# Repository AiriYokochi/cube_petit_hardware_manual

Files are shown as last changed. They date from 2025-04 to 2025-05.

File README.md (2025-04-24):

# cube_petit_hardware_manual

This is Hardware Assembly Manual for Cube petit v3

## Install

https://www.mkdocs.org/getting-started/

```
sudo apt install -y python3-pymdownx
pip install mkdocs
git clone https://github.com/AiriYokochi/cube_petit_hardware_manual.git
cd cube_petit_hardware_manual
mkdocs build
mkdocs serve --dev-addr=0.0.0.0:8000
```

access http://127.0.0.1:8000/

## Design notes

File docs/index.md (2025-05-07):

# Cube petit Hardware Manual
<br>
**Cube petitのハードウェア組み立てマニュアルです。**

完成品は**[こちら](./1_order/3_final_product.md)**から

---
## 基本仕様(ver3.0)
---

- 本体フレーム
    - 材質：アルミニウム
    - 外装：アクリル
    - 重さ：7[kg]
- センサー
    - 2D LiDAR
        - メーカー：
        - モデル：LD19
    - RGB-Dカメラ
        - メーカー:Intel
        - モデル：RealSense D435
        - 解像度：
        - フレームレート：
        - 深度範囲：
    - IMUセンサー
        - メーカー：
        - モデル：
    - AIカメラ
        - メーカー：
        - モデル：OAK-1
    - モータ
        - メーカー：DJI
        - モデル：M2006
    - ディスプレイ
        - HDMI 5inch

<br>

---
## 目次
---

##### [1.部品調達・発注(order)](./1_order/1_order.md)
##### [2.組み立て(assemble)](./2_assemble/2_assemble.md)
##### [3.PC設定&USB配線(pc_setting)](./3_pc_setting/3_pc_setting.md)
##### [4.センサ設定(sensor_setting)](./4_sensor_setting/4_sensor_setting.md)
##### [5.モーター設定(motor_setting)](./5_motor_setting/5_motor_setting.md)
##### [6.デバイステスト(device_test)](./6_device_test/6_device_test.md.md)
---

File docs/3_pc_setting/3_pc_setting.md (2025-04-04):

## PC設定&USB配線
<br>
MiniPCもしくはRaspberryPi5の設定をしてUbuntu24.04を導入します。<br>
Cube petit用のリポジトリをインストールして、次以降の章でセンサやMotorが正常に動くか確認します。
<br>

---
### 手順
---

##### [1.Ubuntu24.04の導入](./3-1.details/3-1_install_ubuntu.md)
##### [2.PCの設定](./3-1.details/3-2_setup_pc.md)
##### [3..ROS2 Jazzy導入](./3-1.details/3-3_setup_ros.md)
##### [4.配線](./3-1.details/3-4_wire.md)

---

**Pages**
[1.部品調達・発注(order)](./1_order/1_order.md)
[2.組み立て(assemble)](./2_assemble/2_assemble.md)
[3.PC設定(pc_setting)](./3_pc_setting/3_pc_setting.md)
[4.センサ設定(sensor_setting)](./4_sensor_setting/4_sensor_setting.md)
[5.モーター設定(motor_setting)](./5_motor_setting/5_motor_setting.md)

---

[indexに戻る](../index.md)

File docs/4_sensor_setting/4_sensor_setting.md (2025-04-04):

## センサー設定
<br>
センサーの設定をします。用途に合わせて必要なセンサを取り付けてください。
<br>

## LiDARの動作確認

LiDARをとPCは図のようにつながっています。

端末で以下のコマンドを叩きます。
```
ros2 launch cube_petit_bringup lidar_check.launch.py
```
画面が出てくるので、LiDARの赤い点が出ていることを確認してください。
確認したら**Ctrl**を押しながら**D**を押して終了します。

#### 動かないとき
LiDARが赤く光っていることを確認してください。

## 深度カメラ(Realsense)の動作確認

RealsenseとPCは図のようにつながっています。

端末で以下のコマンドを叩きます。
```

```
画面が出てくるので、画像が2つ出ていることを確認してください。
確認したら**Ctrl**を押しながら**D**を押して終了します。

#### 動かないとき

## AIカメラの動作確認

AIカメラとPCは図のようにつながっています。

端末で以下のコマンドを叩きます。
```
```
カメラの前で手をかざし、グーチョキパーをして、画面にPEACE,FIVEなどと出ていることを確認してください。
確認したら**Ctrl**を押しながら**D**を押して終了します。

#### 動かないとき

---

[indexに戻る](../index.md)
|[PC設定に戻る](../3_pc_setting.md)
|[次のページ](./3-2_setup_pc.md)

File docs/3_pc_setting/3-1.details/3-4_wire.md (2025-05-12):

## 配線設定

cube-petit用のPCをボディに入れて、USBハブやディスプレイとケーブル接続します。

## 必要なもの
- USBハブ3個(ELECOM, BUFFARO, ANKER)
- USBケーブル
    - typeA - micro-B (0.15[m]x1本) Display電源用
    - typeA - micro B (0.3[m]x1本) LiDAR用
    - typeA - type C (0.3[m]×2本) AIカメラ、CANable(モータ)
    - typeA - type C (0.3[m]×1本) 深度カメラ用
        - (PCにC端子がついていれば)typeC - type C (0.3[m])  
    - モバイルバッテリとPCを繋ぐケーブル(PCによる)
        - DC -> DC もしくは typeC -> typeC など
- HDMIケーブル
- アイソレータ モータ用
- SoundBlaster
- キーボード用のドングル(あれば)
- PC用のモバイルバッテリ PCによる、だいたい19Vで5A程度のもの
- モータ用のモバイルバッテリ 12V DC出力のもの
- 強力両面テープ([Monotaro](https://www.monotaro.com/p/7718/0173/?t.q=3M%2019mm%20%97%BC%96%CA%83e%81%5B%83v))
- 養生など適当なテープ [Monotaro](https://www.monotaro.com/p/0845/9193/?t.q=%97%7B%90%B6%83e%81%5B%83v%81%40%94%92)

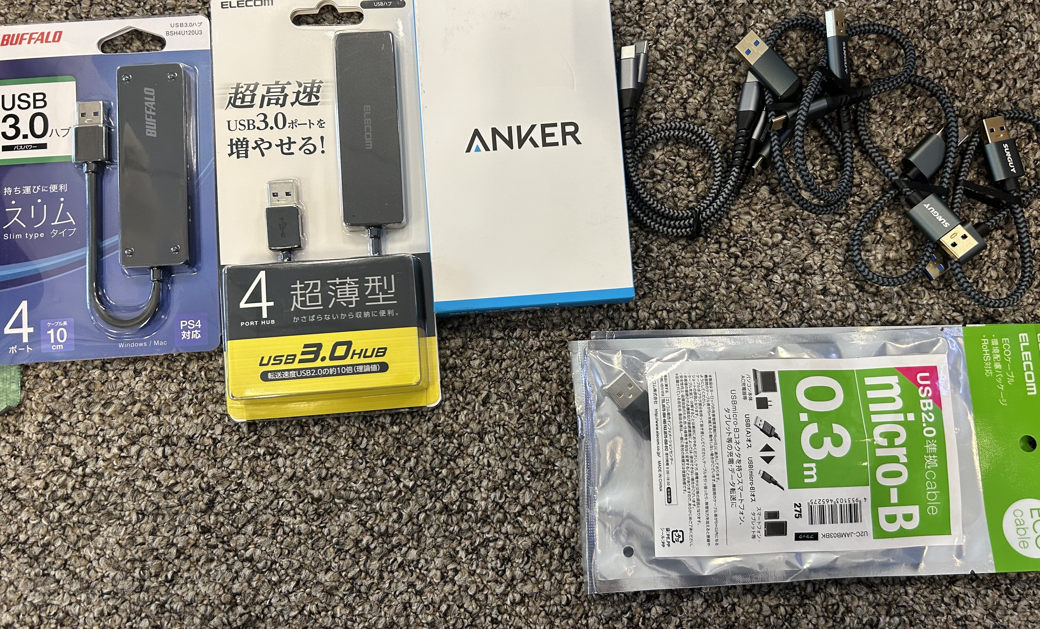
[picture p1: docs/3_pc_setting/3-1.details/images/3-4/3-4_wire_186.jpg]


## 手順①USBハブのとりつけ
ELECOMとBUFFAROのUSBハブに図のように両面テープを取り付けてボディの側面に貼る<br>
ELECOMが外側に来るように貼り付ける

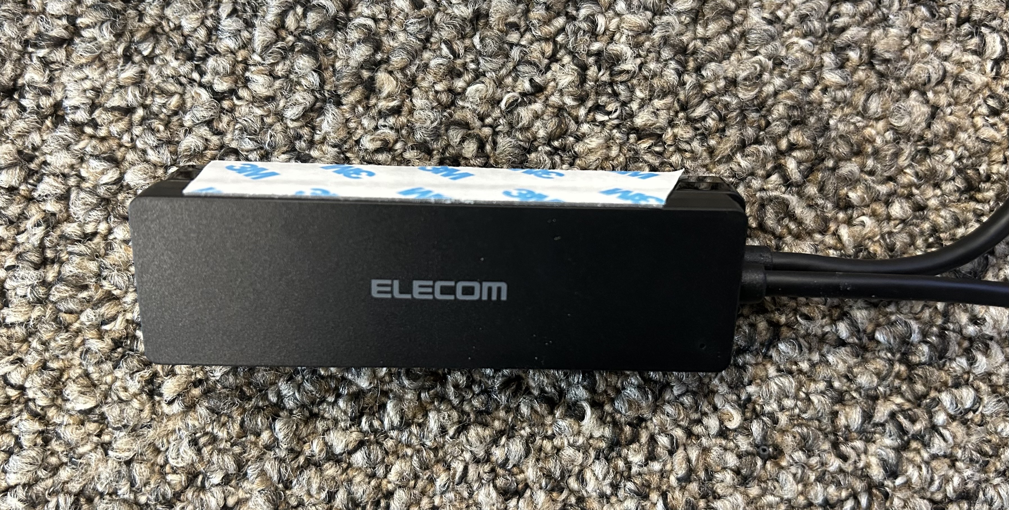
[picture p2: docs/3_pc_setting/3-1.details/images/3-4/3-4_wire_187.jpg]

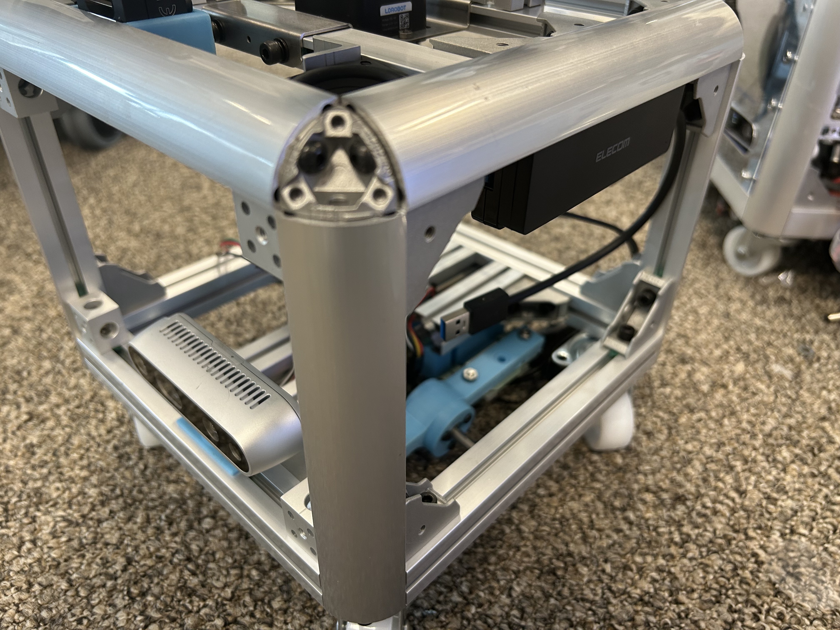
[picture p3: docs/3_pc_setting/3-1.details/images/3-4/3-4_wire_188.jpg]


## 手順②USBハブ配線
PCをボディの中にいれて配線を行います

### BUFFARO
側面1port<br>
- microBケーブル(0.15[m]) --- ディスプレイの電源用<br>

下面3ポート<br>
- typeCケーブル(0.3[m]) --- LiDAR用<br>
- SoundBlaster <br>
- スピーカアンプ<br>

### ELECOM
- typeCケーブル(0.3[m]) --- AIカメラ<br>
- キーボードドングル<br>
- typeCケーブル(0.3[m]) --- 深度カメラ(PCにtypeCポートがない場合)<br>
- ANKERのUSBハブ(PCにUSBポートが2つしかない場合)<br>

### ANKER
- アイソレータ --- typeA-typeC(0.3[m]) CANablePro用<br>

## 手順③HDMIケーブル
HDMIケーブルは写真のようにリボンケーブルを差し込んだら養生テープなどで絶縁しておく

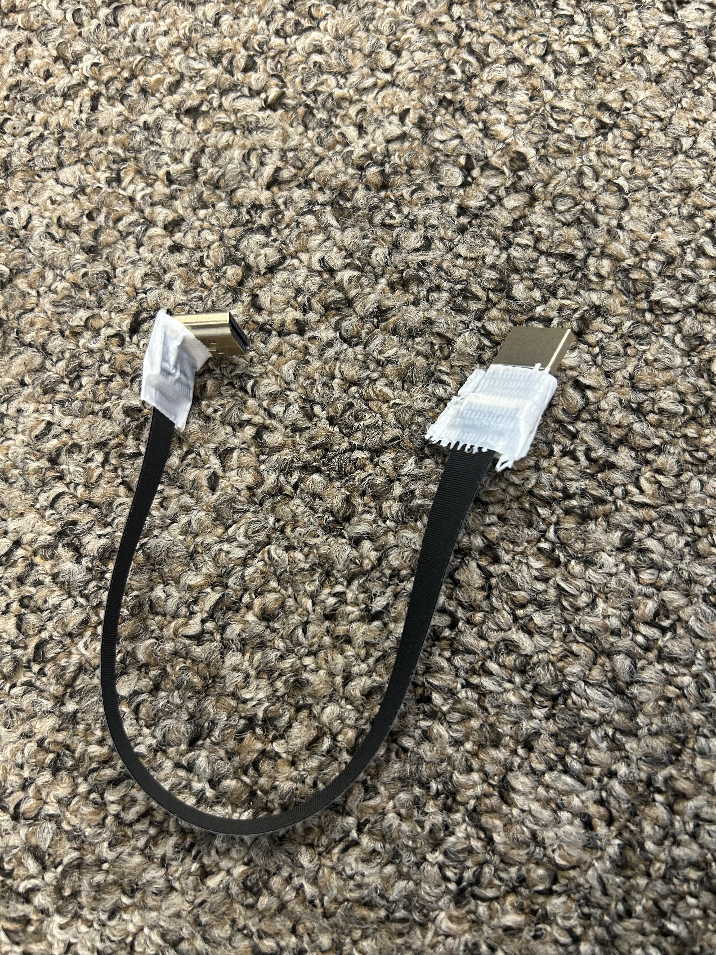
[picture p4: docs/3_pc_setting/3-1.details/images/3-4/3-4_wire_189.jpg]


[indexに戻る](../index.md)
|[PC設定に戻る](../3_pc_setting.md)
|[次のページ](../../4_sensor_setting/4_sensor_setting.md)

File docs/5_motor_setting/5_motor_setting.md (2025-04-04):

## モータ取り付け
<br>
モータの動作確認
<br>

## 必要なもの
- 12Vモバイルバッテリ
- モータ
- モータコントローラ
- PS4or5コントローラ
- アイソレータ

## 配線

## 自動CAN設定

```
ros2 launch cube_petit_hardware_interface cube_petit_control.launch.py
```

---
[indexに戻る](../index.md)

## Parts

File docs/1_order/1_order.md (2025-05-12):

## 部品調達・発注(Order)
<br>

#### **購入したらこちらのページでチェック**→ [次のページ](./2_check.md)

最新のBOMリストを確認してください。

購入するものと、3Dプリンタ及びアクリル板のレーザーカッター発注するものがあります。

部品調達は以下のサイトから行います。それぞれアカウントを作ってください。

- [Amazon](https://www.amazon.co.jp/)
- [Aliexpress](https://ja.aliexpress.com/)
- [Misumi](https://jp.misumi-ec.com/)
- [Monotaro](https://www.monotaro.com/)

---
## 搭載PCの選定について

---
入るサイズであればどのminiPCでもRaspberryPi4,5でも大丈夫ですが、<br>
スペックが低いと**動作が重い**、一定の機能が使えないなどの制限があります。<br>
スペックが高すぎると**バッテリーの持ちが悪くなる**、落ちるといった問題があります。<br>
丁度いいスペックのPCで購入可能なものを探していただけると助かります。<br>

**おすすめの機能**<br>

- サイズは幅12[cm]程度
- 電源を安定させたいならDCジャック、PDでも省電力(TDP15W~25W)のものを
- インターフェース
    - USB type A (3.0)が2個以上
    - HDMI
    - Bluetooth (コントローラとの接続)
    - Wifi (必須)
- CPUスペック
　- AMD Ryzen 7 6800U以下くらいで動きます。
　- GPUはいらないです
- RAM 32GB, SSD 512GB以上

**動作確認済みPC**<br>

- MINIFORUM EM680(2023/4) 参考価格７万円程度
- MINIFORUM S100(2024/4) 参考価格3万円程度(※リアルタイム会話機能が制限されます)
- [TODO]追加

---
## 購入
---

## 工具
ないものは借りるか購入してください
- はんだセット
- ニッパー
- ワイヤーストリッパー
- ヒートガン
- SMコネクタ・MOREXコネクタ用圧着工具

## 🛒 Amazon 購入品
<br>
2025/5月時点 Amazon総額: ¥42,950+(+自由分で ¥107,038)<br><br>

**必須**

  - **ディスプレイ　5inch、左右にHDMI端子がついているもの** – [Amazon](https://www.amazon.co.jp/gp/product/B07FDN3M8H) – ¥5,899

  - **USBハブ① 4portバスパワー(ELECOM)** – [Amazon](https://www.amazon.co.jp/gp/product/B00Y27DEVO) – ¥990

  - **USBハブ② 4portバスパワー(バッファロー)** – [Amazon](https://www.amazon.co.jp/gp/product/B07XPMR5CW) – ¥1,180

  - **USBハブ③ 4portバスパワー(ANKER)** – [Amazon](https://www.amazon.co.jp/Anker-%E3%82%A6%E3%83%AB%E3%83%88%E3%83%A9%E3%82%B9%E3%83%AA%E3%83%A0-%E3%82%B1%E3%83%BC%E3%83%96%E3%83%AB%E3%80%904%E3%81%A4%E3%81%AE-MacBo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) – ￥990

  - **SoundBlaster** – [Amazon](https://www.amazon.co.jp/Creative-Blaster-%E3%82%A4%E3%83%B3%E3%82%BF%E3%83%BC%E3%83%95%E3%82%A7%E3%83%BC%E3%82%B9-%E3%83%8F%E3%82%A4%E3%83%AC%E3%82%BE%E5%86%8D%E7%9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) – ¥1,645

  - **スピーカーアンプ** – [Amazon](https://www.amazon.co.jp/gp/product/B084FRZ4TV) – ¥670

  - **TAMIYA ホイール** – [Amazon](https://www.amazon.co.jp/gp/product/B0000WRY9I) – ¥605

  - **TAMIYA タイヤ** – [Amazon](https://www.amazon.co.jp/gp/product/B0834D138W) – ¥925

  - **TAMIYA タイヤインナー** – [Amazon](https://www.amazon.co.jp/gp/product/B0000WRXVM) – ¥780

  - **TAMIYA 瞬間セッチャク剤 (ゴムタイヤ用]**[Amazon)](https://www.amazon.co.jp/dp/B00061HCDQ/?coliid=I3RERL5PN6Q3JI&colid=58Z7IVI1DNDH&psc=1&ref_=lv_ov_lig_dp_it) ￥495

  - **ばね蝶番** – [Amazon](https://www.amazon.co.jp/gp/product/B00KQFC47G) – ¥1,056（2個）
  
  - **リボンケーブル**  – [Amazon](https://amzn.asia/d/iaFem4J) ￥1,161

  - **12Vモバイルバッテリ×2**  – [Amazon](https://www.amazon.co.jp/%E3%82%B5%E3%83%B3%E3%83%AF%E3%83%80%E3%82%A4%E3%83%AC%E3%82%AF%E3%83%88-%E3%83%A2%E3%83%90%E3%82%A4%E3%83%AB%E3%83%90%E3%83%83%E3%83%86%E3%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) ￥9,970

   - **USBケーブルC-C PD用 0.3[m]** - [Amazon](https://amzn.asia/d/amBpY5x) ￥899

   - **USBケーブルmicroB-A Display用  0.15[m] x1** - [Amazon](https://amzn.asia/d/09TgPOd)  ¥379 1本
   
   - **USBケーブルmicroB-A LiDAR用  0.30[m] x1** - [Amazon](https://amzn.asia/d/8nq8SEj) ¥376 1本

   - **USBケーブルC-A AIカメラ、深度カメラ、MotorController用  0.3[m] x3** - [Amazon](https://amzn.asia/d/1dJWg35)　¥1498 (2個)
   
   - **USBケーブルA-A  0.3[m]** - [Amazon](https://www.amazon.co.jp/GHNTJAP-5Gbps%E9%AB%98%E9%80%9F%E3%83%87%E3%83%BC%E3%82%BF%E8%BB%A2%E9%80%81-%E9%AB%98%E8%80%90%E4%B9%85%E3%83%8A%E3%82%A4%E3%83%AD%E3%83%B3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)　¥699
   
   - **PS4/5コントローラ** - [Amazon](https://www.amazon.co.jp/%E3%82%BD%E3%83%8B%E3%83%BC%E3%83%BB%E3%82%A4%E3%83%B3%E3%82%BF%E3%83%A9%E3%82%AF%E3%83%86%E3%82%A3%E3%83%96%E3%82%A8%E3%83%B3%E3%82%BF%E3%8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) ¥10,613

  - **SMコネクタ 3pinコネクタ (1セット)　ピン・ソケット(6セット)** [Amazon](https://amzn.asia/d/b40fbM0)￥650
  - (スピーカ用) SMコネクタ 2pinコネクタ ピン・ソケット(2セット) 上記に含まれる

**自由**

  - **マイク** – [Amazon](https://www.amazon.co.jp/RODE-Microphones-%E3%83%AD%E3%83%BC%E3%83%89%E3%83%9E%E3%82%A4%E3%82%AF%E3%83%AD%E3%83%95%E3%82%A9%E3%83%B3%E3%82%BA-%E3%83%AF%E3%82%A4%E3%8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) – ¥30,909
  - **モバイルバッテリ PD 140W 20V出力のもの** – [Amazon](https://www.amazon.co.jp/UGREEN-%E4%BD%8E%E9%9B%BB%E6%B5%81%E3%83%A2%E3%83%BC%E3%83%89%E3%83%BB%E3%83%91%E3%82%B9%E3%82%B9%E3%83%AB%E3%83%BC%E6%A9%9F%E8%83%BD%E6%90%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) – ¥13,580
  - **WiFiルータ** – [Amazon](https://www.amazon.co.jp/GL-iNet-GL-MT3000-%E3%83%88%E3%83%A9%E3%83%99%E3%83%ABIPv6%E5%AF%BE%E5%BF%9C-%E3%82%AE%E3%82%AC%E3%83%93%E3%83%83%E3%83%88AX3000-Wireguard/d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) – ¥13,999

  - **ワイヤレスキーボード** – [Amazon](https://www.amazon.co.jp/Logicool-%E3%83%AD%E3%82%B8%E3%82%AF%E3%83%BC%E3%83%AB-%E3%83%AF%E3%82%A4%E3%83%A4%E3%83%AC%E3%82%B9-%E3%82%BF%E3%83%83%E3%83%81%E3%82%AD%E3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) – ¥5,600

---

## 🌏 Aliexpress 購入品
<br>
2025/5月時点 Aliexpress総額: ¥43,521<br><br>

  - **スピーカ** – [Aliexpress](https://ja.aliexpress.com/item/32624188122.html) – ¥3,528（2個）

  - **USB to CAN** – [Aliexpress](https://ja.aliexpress.com/item/1005006008212111.html) – ¥2,163

  - **モータ** – [Aliexpress](https://ja.aliexpress.com/item/1005001417061496.html) – ¥22,626（2個）

  - **モータコントローラ** – [Aliexpress](https://ja.aliexpress.com/item/1005001417061496.html) – ¥13,924（2個）

  - **LiDAR LD19** – [Aliexpress](https://ja.aliexpress.com/item/1005006030979431.html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) – ¥12,388
 https://ja.aliexpress.com/item/1005006030979431.html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
  - **アイソレータ(モータコントローラ用)**  - [Aliexpress)](https://ja.aliexpress.com/item/4000047053305.html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) - ¥874 (1個)

   - **HDMIアダプター** [Aliexpress](https://ja.aliexpress.com/item/1005002393642419.html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) ¥406 (1個)

---

## 🧰 Monotaro 購入品
<br>
2025/5月時点 Monotaro総額: ¥25,462<br><br>

  - **キャスター** – [Monotaro](https://www.monotaro.com/g/00000812/?t.attr_f3506=%82%C8%82%B5&t.attr_f862=50&t.q=%83L%83%83%83X%83%5E%81%5B) – ¥876（4個）

  - **インシュロック** – [Monotaro](https://www.monotaro.com/p/3954/8731/?t.q=%83C%83%93%83V%83%85%83%8D%83b%83N%20%95%9D2.5) – ¥299（4本）

  - **モーターハブシャフト** - [Monotaro](https://www.monotaro.com/p/0568/6406/) - ￥499 (1個)

  - **強力両面テープ** ([Monotaro](https://www.monotaro.com/p/7718/0173/?t.q=3M%2019mm%20%97%BC%96%CA%83e%81%5B%83v)) ￥1,498 1個

  - **養生など適当なテープ** [Monotaro](https://www.monotaro.com/p/0845/9193/?t.q=%97%7B%90%B6%83e%81%5B%83v%81%40%94%92) ￥459 1個

### ねじ
- M4
    - 六角穴付ボルト / 素材：(SCM435/黒色酸化皮膜) / 全ねじ / 滑り止め付き / 長さ10[mm] (82本)：アルミフレーム組み立て用＋センサパーツ取付用 [Monotaro](https://www.monotaro.com/g/00010518/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) 2個 ￥1498
    - 六角穴付ボルト/ 素材：ステンレス / 全ねじ / 長さ35[mm] (8本)：足回り取り付け用　[Monotaro](https://www.monotaro.com/p/6891/0704/?t.q=%98Z%8Ap%8C%8A%95t%83%7B%83%8B%83g%81%40M4) 1個 ￥1,298
    - 六角穴付ボルト / 素材：ステンレス / 全ねじ/ 長さ8[mm] / (8本) : 四角ブラケット取付用 [Monotaro](https://www.monotaro.com/p/2901/7775/?t.q=%98Z%8Ap%8C%8A%95t%83%7B%83%8B%83g%81%40M4) 1個 ￥729
    - 六角穴付ボルト/ 素材：ステンレス / 全ねじ / 長さ16[mm] (8本)：足回り取り付け用 [Monotaro](https://www.monotaro.com/p/2901/7818/?t.q=%98Z%8Ap%8C%8A%95t%83%7B%83%8B%83g%81%40M4) 1個 ￥729
    - 六角穴付ボルト / 極低頭 / 素材:SHSS  / 長さ10[mm] (2本) [Monotaro](https://www.monotaro.com/p/4927/7864/) ￥749
    - 六角穴付ボルト / 極低頭 / 素材:SHSS  / 長さ16[mm] (2本) [Monotaro](https://www.monotaro.com/p/4927/7882/) ￥839
    - 六角穴付ボルト / 極低頭 / 素材:SHSS  / 長さ8[mm] (20本:外装)(12本:キャスタ用) [Monotaro](https://www.monotaro.com/p/4927/7907/) 2セット ¥1418 

- M3
    -  六角穴付ボルト / 極低頭 /  素材：(SCM435/黒色酸化皮膜) / 全ねじ / 長さ8[mm] (6本)：モータ取り付け用 [Monotaro](https://www.monotaro.com/p/4927/7121/?t.q=M3%81%40%8B%C9%92%E1%93%AA) ￥449

- M2.5
    - 六角穴付きボルト / 素材：(SCM435/黒色酸化皮膜) / 全ねじ / 長さ6[mm] (3本)：LiDAR取り付け用 [Monotaro](https://www.monotaro.com/p/6890/8796/?t.q=%98Z%8Ap%8C%8A%95t%83%7B%83%8B%83g%81%40M4) 1個 　￥718
    - 六角穴付きボルト / 素材：(SCM435/黒色酸化皮膜) / 全ねじ / 長さ6[mm] (2本)：画面取り付け用　上に含む
　
- M6 ( or 1/4インチねじ)　※どちらでも可
    - 六角穴付きボルト / 素材：ステンレス / 全ねじ /　8[mm] (1本):深度カメラ用 [Monotaro](https://www.monotaro.com/p/2901/7924/) ￥729
    - 六角穴付きボルト / 素材：(SCM435/黒色酸化皮膜) / 全ねじ/　5[mm] (1本):AIカメラ用 [Monotaro(ステンレス・6mm)](https://www.monotaro.com/p/6891/0765/?t.q=%98Z%8Ap%8C%8A%95t%83%7B%83%8B%83g%81%40M6x5)￥1,198

### ナット・ワッシャー
- M4四角ナット・ナットホルダー(106個)：アルミフレーム組み立て用 - [Misumi](https://jp.misumi-ec.com/vona2/detail/221005480697/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) ￥3912 3セット
- M4後入れナット(あると便利) - [Misumi](https://jp.misumi-ec.com/vona2/detail/221005480552/?Brand=NIQ1&CategorySpec=00000173459%3A%3Ab) ￥1730 10個
- M4ワッシャー(12個) ：キャスター取り付け用 [Monotaro](https://www.monotaro.com/p/0553/0104/?t.q=M4%83%8F%83b%83V%83%83%81%5B) ￥869
- M4スプリングワッシャー(8個:足回り取り付け用)(12個:キャスター取り付け用) [Monotaro](https://www.monotaro.com/p/4552/2951/?t.q=M4%83%8F%83b%83V%83%83%81%5B) ￥599
- M4ナット (8個:足回り取り付け用)(6個 : 画面取り付け用)　[Monotaro](https://www.monotaro.com/p/2876/3457/?t.q=M4%83i%83b%83g%201%8E%ED) ￥209
- M2.5ナット (3個: LiDAR取り付け用)(2個: 画面取り付け用) [Monotaro](https://www.monotaro.com/p/2876/3430/?t.q=M4%83i%83b%83g%201%8E%ED)￥499

### ケーブル

**モータコントローラ用**
- リボンケーブル [Monotaro](https://www.monotaro.com/p/3496/3345/?t.q=%83%8A%83%7B%83%93%83P%81%5B%83u%83%8B) ￥1,498 1個
- ケーブル AWG20 / 赤緑黒 / [Monotaro](https://www.monotaro.com/p/6242/7059/) ¥899 1個
- DCプラグ丸形(Φ5.5×2.5mm) [Monotaro](https://www.monotaro.com/p/7592/9183/?t.q=DC%93d%8C%B9%83R%83l%83N%83%5E%81%402.5) ￥209, 1個

### 熱収縮チューブ
**モータコントローラ用**
- 透明 / Φ21 / [Monotaro](https://www.monotaro.com/p/5513/6506/) ¥389 1個
- 赤と黒 / Φ6.5 / [Monotaro](https://www.monotaro.com/p/3559/8166/?t.q=%94M%8E%FB%8Fk%83%60%83%85%81%5B%83u%81%40%90%D4) ¥999 1個

## 🛒 Misumi 購入品
<br>
2025/5月時点 Misumi総額: ¥24,973<br><br>

- **コネクタ(モータコントローラ用)**
  - Morex 3.5mmピッチ 電線対基板用 ウエハー ライトアングルタイプ 3pin 53259-0329 (1個) - [Misumi](https://jp.misumi-ec.com/vona2/detail/222000581572/?ProductCode=53259-0329) 92円 1個

- **ベーシックフレーム M4 シリーズ ヘビー級 AFS-2020-4**
  - 品物型番: AFS-2020-4-70
  - サイズ: 70mm
  - 個数: 4
  - 総計: 365円
  - 購入先: [Misumi](https://jp.misumi-ec.com/vona2/detail/221005477019/)

- **ベーシックフレーム M4 シリーズ ヘビー級 AFS-2020-4**
  - 品物型番: AFS-2020-4-45-T
  - サイズ: 45mm
  - 個数: 2
  - 総計: 429円
  - 購入先: [Misumi](https://jp.misumi-ec.com/vona2/detail/221005477019/)

- **コーナージョイント M4シリーズ**
  - 品物型番: CJR-2020-4
  - サイズ: 記載なし
  - 個数: 8
  - 総計: 4,092円
  - 購入先: [Misumi](https://jp.misumi-ec.com/vona2/detail/221005481654/)

- **ベーシックフレーム M4シリーズ ヘビー級 AFS-1020-4**
  - 品物型番: AFS-1020-4-180
  - サイズ: 180mm
  - 個数: 4
  - 総計: 832円
  - 購入先: [Misumi](https://jp.misumi-ec.com/vona2/detail/221005476984/)

- **M4シリーズ デルタブラケット ABLD-20-4**
  - 品物型番: ABLD-20-4-T
  - サイズ: 記載なし
  - 個数: 36
  - 総計: 9,504円
  - 購入先: [Misumi](https://jp.misumi-ec.com/vona2/detail/221005480743/)

- **M4シリーズ ブロックブラケット ABLB**
  - 品物型番: ABLB-2015-4-T
  - サイズ: 記載なし
  - 個数: 4
  - 総計: 2,240円
  - 購入先: [Misumi](https://jp.misumi-ec.com/vona2/detail/221005481430/)

- **M4シリーズ スタンダードブラケット ABL**
  - 品物型番: ABL-2015-4
  - サイズ: 記載なし
  - 個数: 4
  - 総計: 1,320円
  - 購入先: [Misumi](https://jp.misumi-ec.com/vona2/detail/221005480798/)

- **ベーシックフレーム M4シリーズ ヘビー級 AFSR-2020**
  - 品物型番: AFSR-2020-4-150-W
  - サイズ: 150mm
  - 個数: 4
  - 総計: 1,659円
  - 購入先: [Misumi](https://jp.misumi-ec.com/vona2/detail/221005477109/)

- **ベーシックフレーム M4シリーズ ヘビー級 AFSR-2020**
  - 品物型番: AFSR-2020-4-180-W
  - サイズ: 180mm
  - 個数: 8
  - 総計: 3,494円
  - 購入先: [Misumi](https://jp.misumi-ec.com/vona2/detail/221005477109/)

- **ベーシックフレーム M4シリーズ ヘビー級 AFSF-2020**
  - 品物型番: AFSF-2020-4-180
  - サイズ: 180mm
  - 個数: 4
  - 総計: 946円
  - 購入先: [Misumi](https://jp.misumi-ec.com/vona2/detail/221005477086/)

---

## 発注データ

---

## 金属板(Misumi)
[Misumi meviy](https://meviy.misumi-ec.com/ja-jp/)で発注してください。
<br>

| 名前|加工方法　 | 材質 　　| 表面処理　　　  | 個数 　|備考 | 
| -- | -- | -- | -- | -- | -- |
| [LiDAR_LD19_plate](./Metal_parts/) | 板金 |SUS304(2B) | なし |1 | LiDAR用
| [L_bracket_2](./Metal_parts/) | 板金 | A5052| アルマイト(白) |2  | 天板取り付け用L字ブラケット |
| [T_bracket_2](./Metal_parts/) | 板金 | A5052| アルマイト(白) | 2 | 天板取り付け用T字ブラケット |
| [hinge_metal_holder_1_x4](./Metal_parts/) | 板金 | A5052| アルマイト(白)| 4 | 蝶番取り付け用
| [hinge_metal_holder_2_x4](./Metal_parts/) | 板金 | A5052| アルマイト(白) | 4 | 蝶番取り付け用

<br>

---

## 3Dパーツ(どこでも可)
<br>
材質はPLAもしくはABSなどでお好きな色で発注してください

| 名前　　　 | 個数　　| 備考 |
| -- | -- | -- |
| [hinge_holder_x4](./3D_printing_parts/hinge_holder_x4.stl) | 4 | 蝶番取り付け
| [M2006p36?holder_x2](./3D_printing_parts/M2006p36_holder_x2.stl) | 2 | モーター取り付け
| [oak-1-mount_x1](./3D_printing_parts/oak-1-mount_x1.stl) | 1 | AIカメラ取り付け
| [realsense_mount_x1](./3D_printing_parts/realsense_mount_x1.stl) | 1 | 深度カメラ取り付け

---

## アクリル板(どこでも可)
Monotaroやはざいやなどでお好きな色＋透明の板を購入してカット処理を頼むか、<br>
素材は買わずにMisumiにある中から発注してください。

**①自作例　Monotaro(クリアブルー)**<br>
Monotaroで素材を買う例

| 名前 | メーカー | 型番　　　 | サイズ　　　 | 個数　 | 購入先URL |
| -- | -- | -- | -- | -- | -- |
| アクリル板(ライトブルー) | 光 | A700-2S | 厚さ2mm幅320mm長さ545mm | 1 | [MONOTARO](https://www.monotaro.com/p/4031/9517/) |
| アクリル板(ライトブルー) | 光 | A700-3S | 厚さ3mm幅320mm長さ545mm | 2 |  [MONOTARO](https://www.monotaro.com/p/8625/7614/) |
| アクリル板 透明色 | 光 | A000-3S | 厚さ3mm幅320mm長さ545mm | 3 | [MONOTARO](https://www.monotaro.com/p/0701/5775/) |
| アクリル板(透明) | ノーブランド | |厚さ1mm幅400mm長さ400mm | 1 | [MONOTARO](https://www.monotaro.com/p/4554/7372/) |

<br>

**②自作例　はざいや**<br>
パステルカラーは[はざいや](https://www.hazaiya.co.jp/)もおすすめ。<br>
レーザーカッターに入るように450mm*550mm 程度までのサイズにすること。

|材質　　　　| 色 　　　　|厚み[mm] |サイズ[mm]　　　　　　　　　　|枚数　|用途|
| --- | --- | --- | --- | ---|---|
|アクリル| 好きな色 | 2| 200x150~550x450 | 1 | 顔前面の外装
|アクリル| 好きな色 | 3 | 200x450~550x450 | 2 | 側面及び上面の外装
|アクリル| 透明 | 1 | 200x150~550x450 | 1 | 顔前面のカバー
|アクリル | 好きな色 | 3 | 200x150~550x450  | 1 | センサ・ディスプレイの

<br>

**③完全発注　Minumi meviy2D**

[Misumi meviy](https://meviy.misumi-ec.com/ja-jp/2dx/meviy2d/)にアクセスして
見積もり＆発注してください。好きなカラーで大丈夫です。

---

**Cutデータ(寸法付き、、Misumi発注用)**
<br>

| 名前 | 色 | 厚み[mm] | 個数 |　備考 | 
| -- | -- | -- | -- | -- |
| [out_top_color_3mm_size.dxf](./Laser_Cut_parts/) | 色付き |3mm | 1 | 外装天板 | 
| [out_side_color_3mm_size.dxf](./Laser_Cut_parts/) | 色付き |3mm | 3 | 外装側面 |
| [face1_clear_1mm_size.dxf](./Laser_Cut_parts/) | 透明 | 1mm | 1 | 外装顔1 |
| [face2_color_2mm_size.dxf](./Laser_Cut_parts/) | 色付き | 2mm | 1 | 外装顔2 |
| [display1_clear_3mm_size.dxf](./Laser_Cut_parts/) | 透明 | 3mm | 1 | ディスプレイ取り付け用 |
| [display2_clear_3mm_size.dxf](./Laser_Cut_parts/) | 透明 | 3mm | 2 | ディスプレイ取り付け用 |

<br>

**Cutデータ(寸法なし、自分でLaserCutする用)**
<br>

| 名前 | 色 | 厚み[mm] | 個数 |　備考 | 
| -- | -- | -- | -- | -- |
| [out_top_color_3mm.dxf](./Laser_Cut_parts/sketch/out_top_color_3mm.dxf) | 色付き |3mm | 1 | 外装天板 | 
| [out_side_color_3mm_x2.dxf](./Laser_Cut_parts/sketch/out_side_color_3mm_x3.dxf) | 色付き |3mm | 3 | 外装側面 |
| [face1_clear_1mm.dxf](./Laser_Cut_parts/sketch/face1_clear_1mm.dxf) | 透明 | 1mm | 1 | 外装顔1 |
| [face2_color_2mm.dxf](./Laser_Cut_parts/sketch/face2_color_2mm.dxf) | 色付き | 2mm | 1 | 外装顔2 |
| [display1_clear_3mm_.dxf](./Laser_Cut_parts//sketch/display1_clear_3mm.dxf) | 透明 | 3mm | 1 | ディスプレイ取り付け用 |
| [display2_clear_3mm_x2.dxf](./Laser_Cut_parts/sketch/display2_clear_3mm_x2.dxf) | 透明 | 3mm | 2 | ディスプレイ取り付け用 |

---

[indexに戻る](../index.md)|[次のページ](./2_check.md)

---

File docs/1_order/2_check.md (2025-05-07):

## 部品チェック(Check)
<br>
購入したもの・発注したものが届いたら必要なものをチェックします。<br>
組み立てやすくするために部材を分けておくのがおすすめです。

#### **オーダーページ**→ [前のページ](./1_order.md)

<br>
---

### アルミフレーム
26本あることを確認します。

| ✅ | 断面の形 | 長さ[mm] | 本数 | 
| --- | --- | --- | --- |
| | R型 | 180  | 8 |
| | R型 | 150 | 4
| | 薄型 | 180 | 4 | 
| | 正方形 | 180 | 4 |
| | 正方形 | 70 | 4 |
|  | 正方形 | 45 | 2 |

左上から
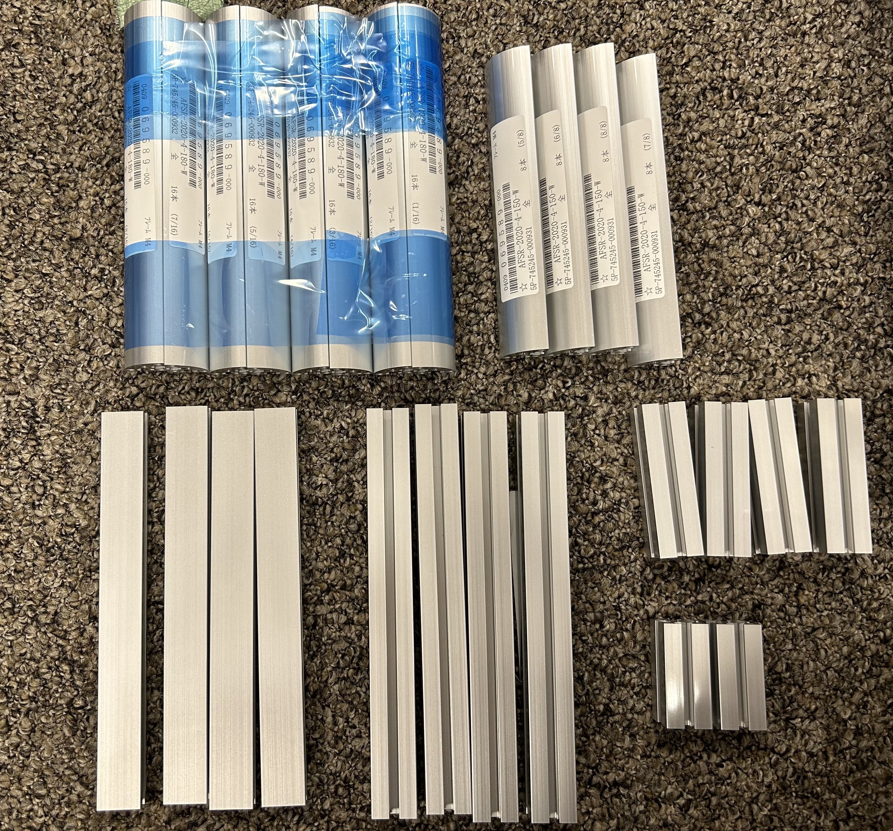
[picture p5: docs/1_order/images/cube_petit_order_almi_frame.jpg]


### アルミブラケット類・金属バーツ
以下があることを確認します

| ✅ | 形の説明 | 個数 |
| --- | --- | --- |
| | 顔面用の四角いブラケット | 4 | 
| | 三角のブラケット| 30 | 
| | L字のブラケット| 2 |
| | 角用の丸形ブラケット| 8 | 
| | LiDARマウント用金属パーツ | 1 |
| | 頭取り付け用用金属パーツ(T型) | 2 |
| | 頭取り付け用用金属パーツ(L型) | 2 |
| | 足回り用金属パーツ(小) | 4 | 
| | 足回り用金属パーツ(大) | 4 |

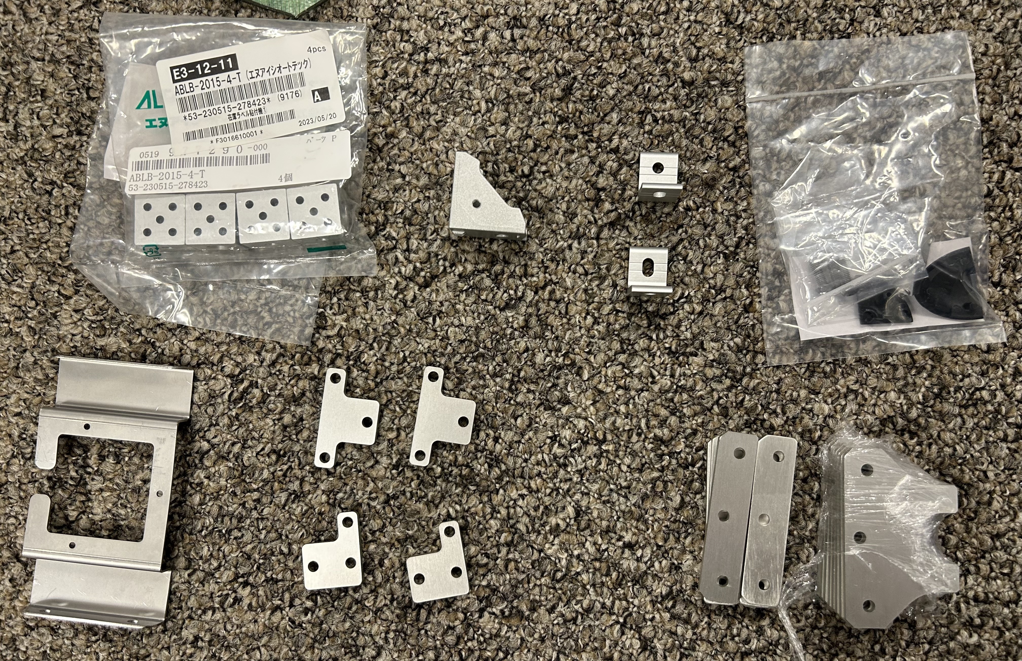
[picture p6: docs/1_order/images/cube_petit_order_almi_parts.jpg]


### 3Dプリンタ部品
以下があることを確認します

| ✅ | 説明 | 個数 | 
| --- | --- | --- |
|  | モータ取り付け用パーツ | 2 |
| | 足回り取り付けパーツ | 4 |
| | AIカメラ取り付けパーツ |1|
| | 深度カメラ取り付けパーツ | 1 |

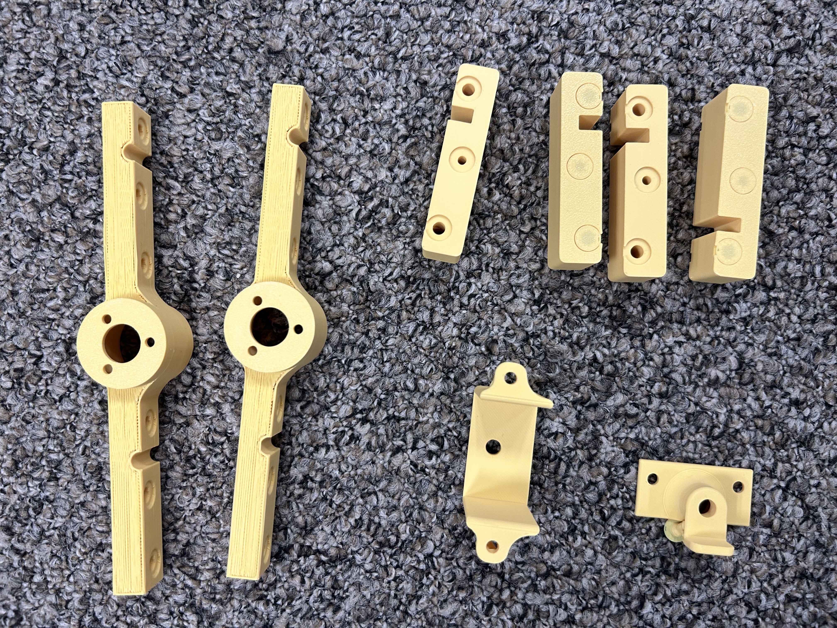
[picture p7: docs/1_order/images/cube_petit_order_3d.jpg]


### カメラ・センサ類
以下があることを確認します

| ✅ | 説明 | 個数 | 
| --- | --- | --- |
| | 深度カメラ(Realsense) |1|
| | AIカメラ(OAK-1) | 1 |
|  | LiDAR | 1 |

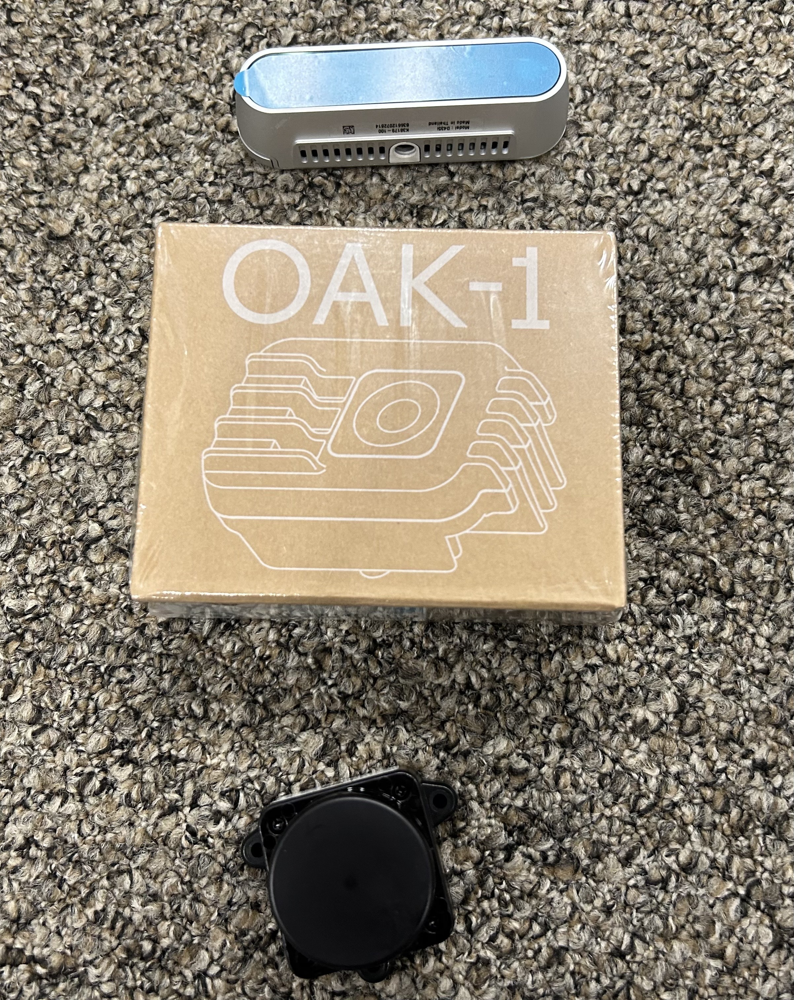
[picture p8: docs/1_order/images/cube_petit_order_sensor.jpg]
)

### 足回り部品
以下があることを確認します

| ✅ | 説明 | 個数 | 
| --- | --- | --- |
| | バネ蝶番 |4 |
| | インシュロック | 4 | 
| | キャスタ |4 |
| | モータ(M2006 P36) | 2 |
|  | モータコントローラ(C610) | 2 |
| | USBtoCAN(CANablePro) |1 |
| | ホイールインナー |2 |
| | ホイール |2 |
| | タイヤ |2 |
| | アイソレータ |1 |

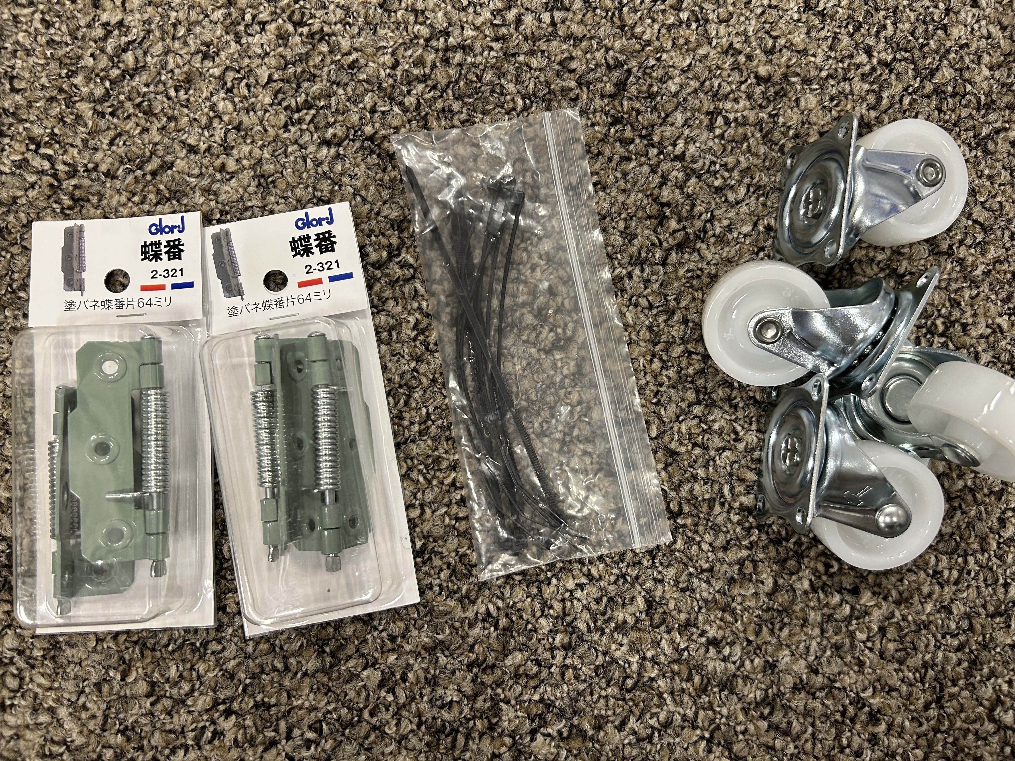
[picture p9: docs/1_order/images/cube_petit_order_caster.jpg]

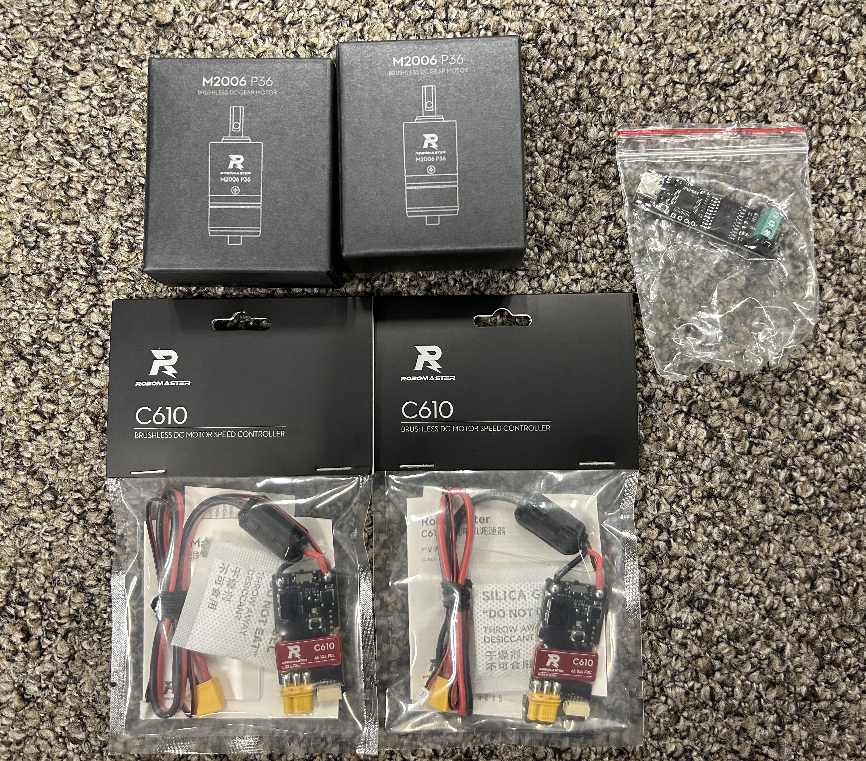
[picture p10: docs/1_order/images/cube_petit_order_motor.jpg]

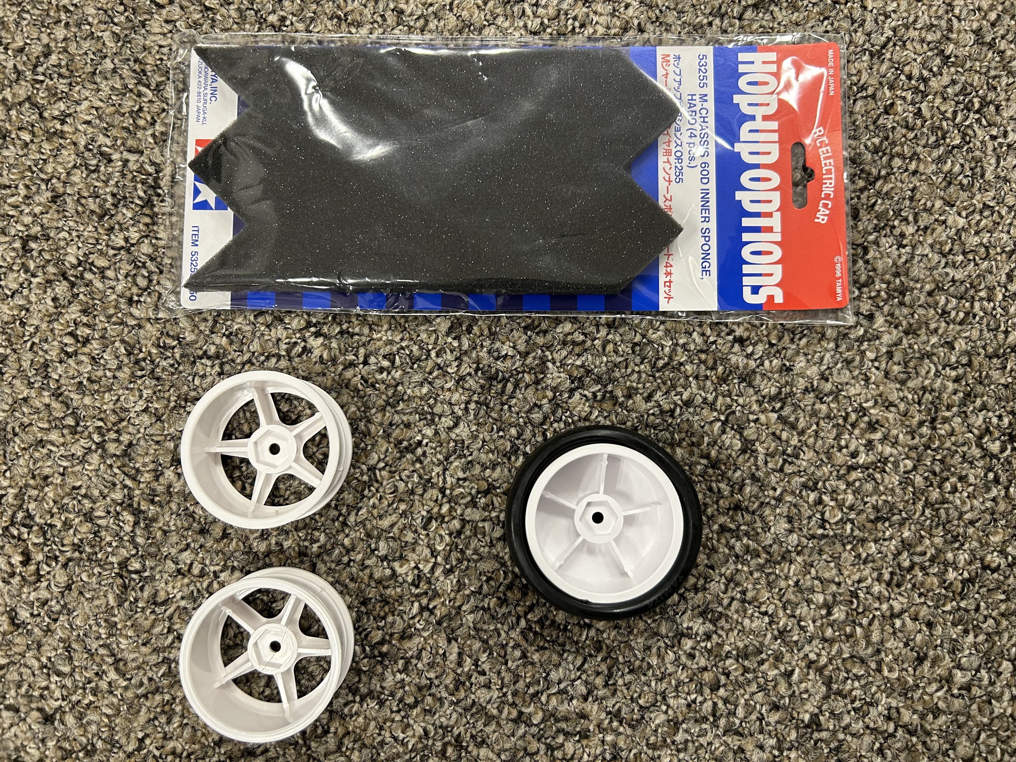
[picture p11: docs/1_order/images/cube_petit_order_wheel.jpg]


[TODO] アイソレータ・ホイールが来たら写真を更新する

### アクリル板
写真のように8枚があることを確認します

### ディスプレイ関連
写真のようにあることを確認します

| ✅ | 説明 | 個数 | 
| --- | --- | --- |
| | HDMIリボンケーブル1 | 1 |
| | HDMIリボンケーブル2 | 1 |
|  | ディスプレイ(ELECROW) | 1 |

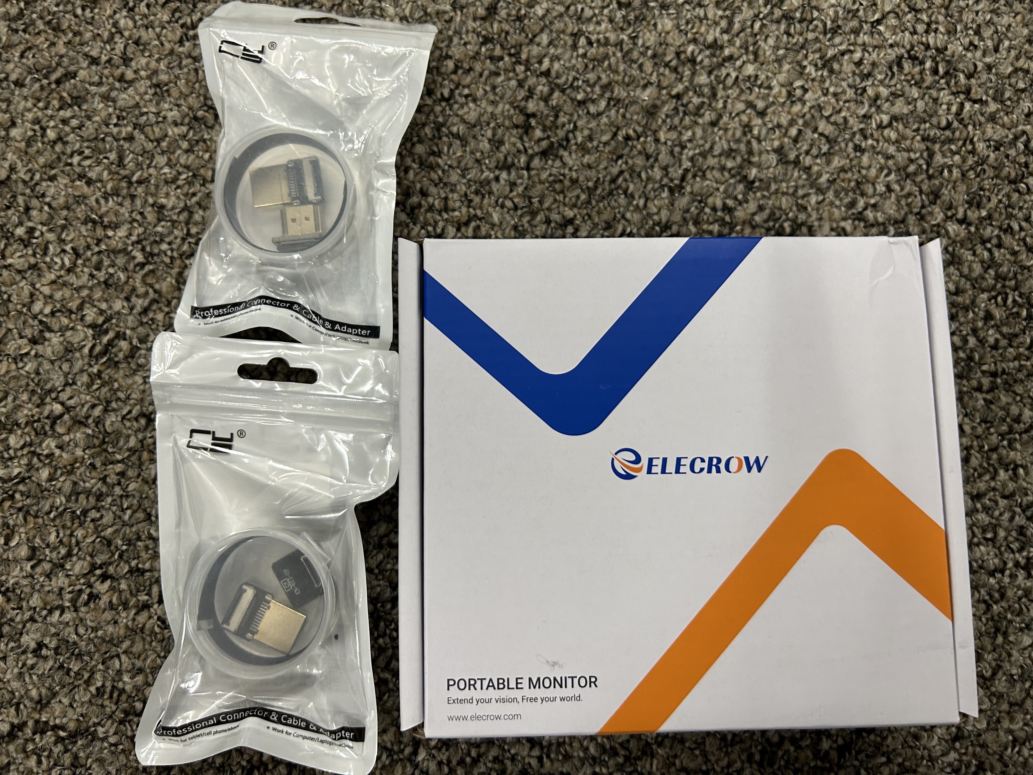
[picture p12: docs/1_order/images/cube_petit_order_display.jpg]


### USBケーブル・ハブ
写真のようにあることを確認します

| ✅ | 説明 | 個数 | 
| --- | --- | --- |
|  | A-A | | 
|  | A-microB | 2 |
|  | A-C | |
|  | バッファローのUSBハブ4Port |1|
|  | ELECOMのUSBハブ4Port | 2 |

### スピーカ・マイク
写真のようにあることを確認します

| ✅ | 説明 | 個数 | 
| --- | --- | --- |
|  | スピーカアンプ | 1 |
|  | スピーカ| 2 | 
|  | USB(Sound Braster!) | 1 |
|  | マイク | 1 |



[TODO] マイクの写真を追加

### PC・バッテリ関連
写真のようにあることを確認します

| ✅ | 説明 | 個数 | 
| --- | --- | --- |
|  | PC| 1 | 
|  | モバイルバッテリ | 1 |
|  | PC-モバイルバッテリのケーブル | 1 |

### ねじ・ナット・コネクタ

写真のように仕分けをしておくと楽です。<br>

アルミフレーム組み立て用<br>

その他パーツ組み立て用<br>


### 熱収縮チューブ
写真のようにあることを確認します

### ケーブル
写真のようにあることを確認します

---
[前のページ](./1_order.md) | [indexに戻る](../index.md) | [次のページ](../2_assemble/2_assemble.md)

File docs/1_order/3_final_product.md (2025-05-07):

## 完成品
フルキットです。PC・バッテリは要望に応じ選定し初期設定を行います<br>
[こちらのページ](./1_order.md)を参考にPCとバッテリの選定をしてください<br>

写真
※工場発注準備中(値段61万円程度)
<br><br>
**内訳**<br>
部品購入代(¥200,000)<br>
3Dプリント部品発注代(¥80,000)<br>
アクリル板発注代(¥80,000)<br>
金属部品発注代(¥130,000)<br>
PC購入+セットアップ代(¥100,000)<br>
バッテリ購入代(¥20,000)<br>
＋送料

選択可能オプション<br>
(センサはデフォルトですべてつきますが好きな機種がある場合は不要と書いてください。<br>部品代より値引きします)<br>

- センサ
    - [ ] AIカメラ:画像認識用<br>
    - [ ] 深度カメラ:自律移動用<br>
- 外装色<br>
    - [ ] クリアブルー<br>
    - [ ] クリアピンク<br>
    - [ ] クリアオレンジ<br>
    - [ ] アイボリー<br>
    - [ ] 白<br>
    - [ ] 黒<br>

---

## セミオーダー
必要なものは六角レンチのみで完成するキットです<br>
部品の注文・はんだづけ、熱収縮などの工程済み<br>
PC・バッテリは付属していません<br>

選択可能オプション(デフォルトでつきますが好きな機種がある場合は不要と書いてください。<br>部品代より値引きします)<br>
- [ ] AIカメラ:画像認識用<br>
- [ ] 深度カメラ:自律移動用<br>

写真<br><br>
※工場発注準備中(値段49万円程度)

**内訳**<br>
部品購入代(200,000)<br>
3Dプリント部品発注代(¥80,000)<br>
アクリル板発注代(¥80,000)<br>
金属部品発注代(¥130,000)<br>
＋送料

---

## DIY
35万円<br><br>
**内訳**<br>
部品購入代(¥140,000 ~ ¥200,000)<br>
3Dプリント部品代(¥0~ [DMM](https://lp.make.dmm.com/)の見積もりでは¥22,264)<br>
アクリル板代(~¥20000程度)<br>
金属部品発注代(¥0~Misumi meviyでは¥41,250)<br>
PC代(¥60,000~¥100,000)
バッテリ代(¥20,000)
+工具や設備代

---

## 問い合わせ先
at→`@`, dot→`.`

Mail: airi`<dot>`yokochi`<at>`g`<dot>`softbank`<dot>`co`<dot>`jp

[indexへもどる](./../index.md)

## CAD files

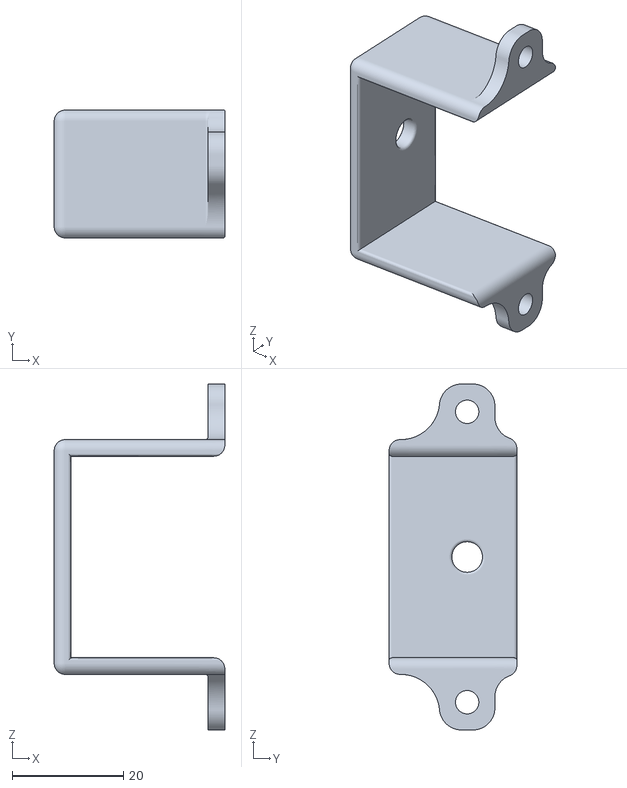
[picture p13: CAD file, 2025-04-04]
docs/1_order/3D_printing_parts/oak-1-mount_x1.stl
30.7 x 23.0 x 62.2

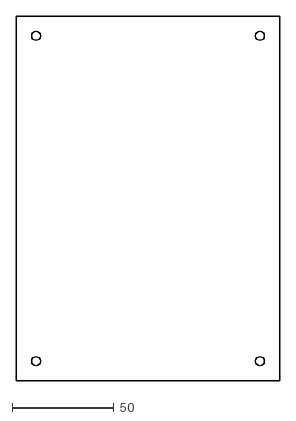
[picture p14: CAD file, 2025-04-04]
docs/1_order/Laser_Cut_parts/sketch/out_side_color_3mm_x3.dxf
129.4 x 179.4

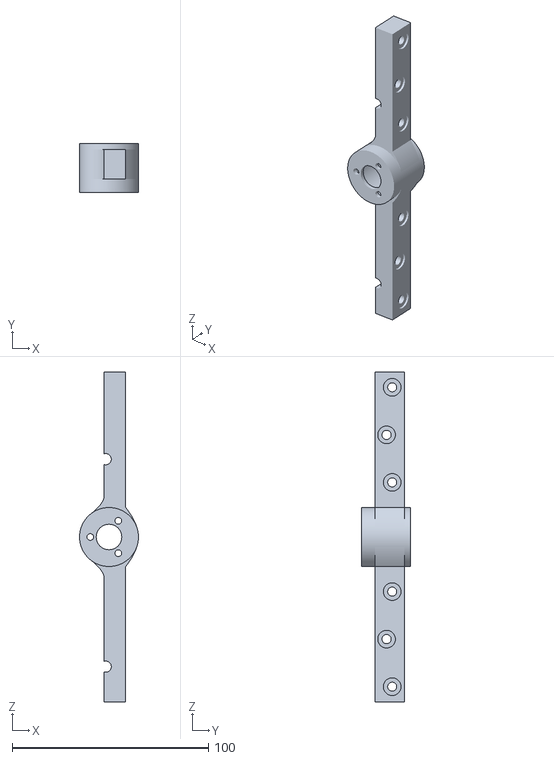
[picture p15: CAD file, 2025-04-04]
docs/1_order/3D_printing_parts/M2006p36_holder_x2.stl
30.0 x 25.0 x 168.0

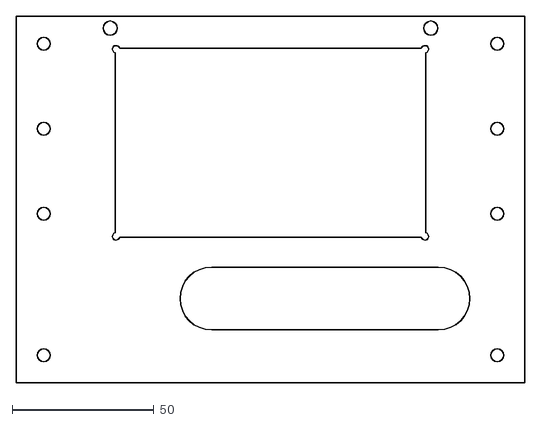
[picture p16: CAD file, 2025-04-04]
docs/1_order/Laser_Cut_parts/sketch/face2_color_2mm.dxf
179.4 x 129.4

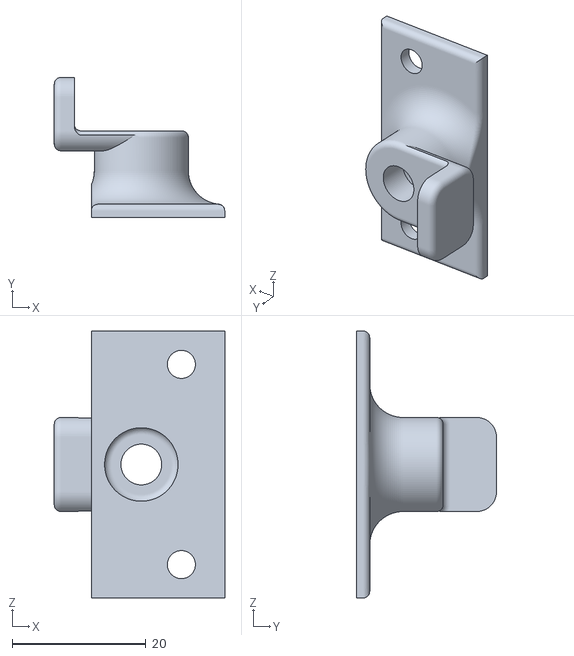
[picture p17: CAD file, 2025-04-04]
docs/1_order/3D_printing_parts/realsense_mount_x1.stl
25.6 x 21.0 x 40.0

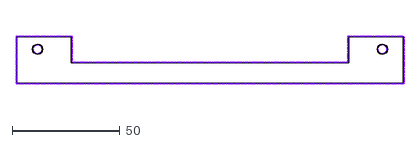
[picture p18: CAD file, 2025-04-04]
docs/1_order/Laser_Cut_parts/sketch/display2_clear_3mm_x2.dxf
180.0 x 22.0

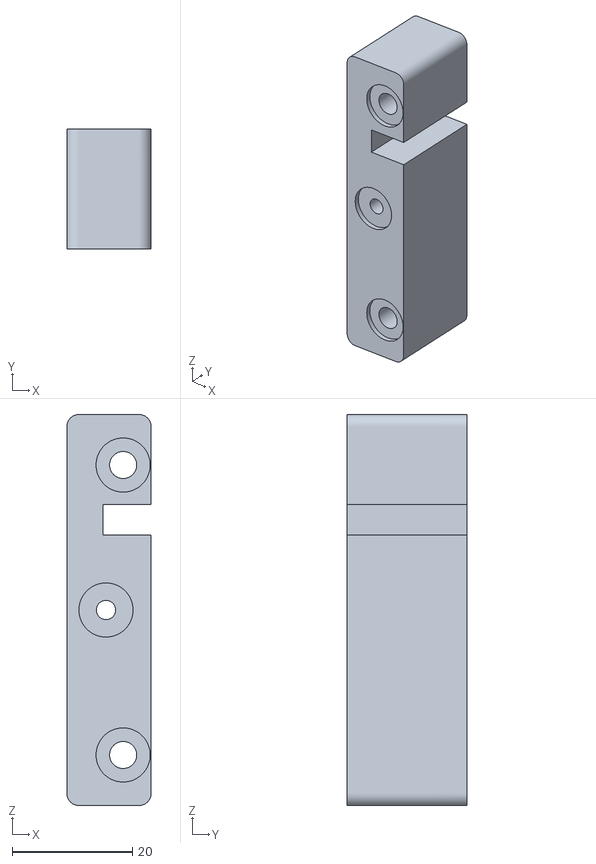
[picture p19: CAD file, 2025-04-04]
docs/1_order/3D_printing_parts/hinge_holder_x4.stl
14.0 x 20.0 x 65.0

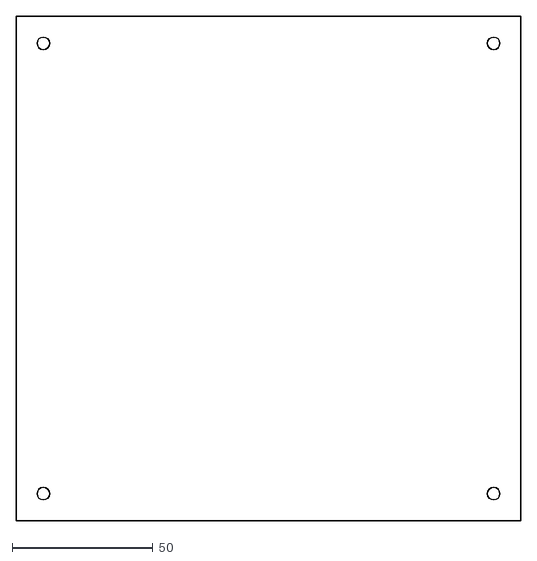
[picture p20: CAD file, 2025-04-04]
docs/1_order/Laser_Cut_parts/sketch/out_top_color_3mm.dxf
179.4 x 179.4

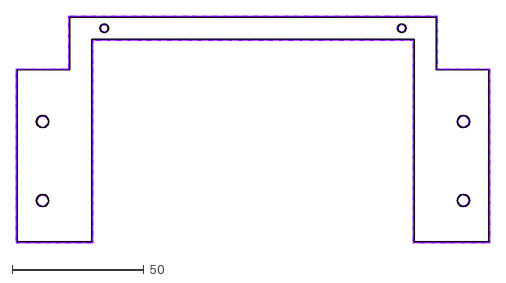
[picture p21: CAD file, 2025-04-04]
docs/1_order/Laser_Cut_parts/sketch/display1_clear_3mm.dxf
180.0 x 86.0

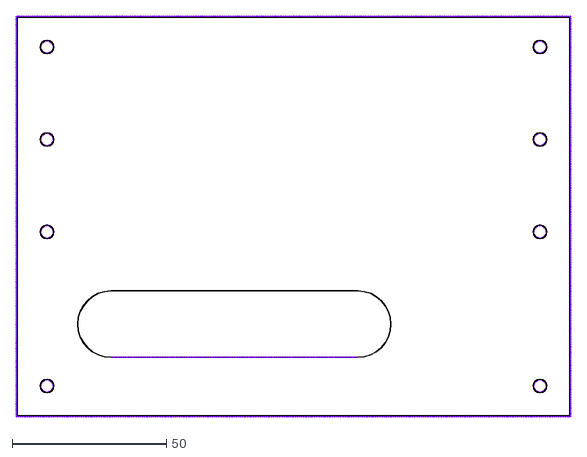
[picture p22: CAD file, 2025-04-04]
docs/1_order/Laser_Cut_parts/sketch/face1_clear_1mm.dxf
180.0 x 130.0

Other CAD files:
docs/1_order/Laser_Cut_parts/sized/3mm_clear_display1_size_x1.dwg
docs/1_order/Laser_Cut_parts/sized/1mm_clear_face1_size_x1.dwg
docs/1_order/Laser_Cut_parts/sized/3mm_clear_display2_size_x1.dwg
docs/1_order/Laser_Cut_parts/sized/3mm_color_out_top_size_x1.dwg
docs/1_order/Laser_Cut_parts/sized/3mm_color_out_side_size_x3.dwg
docs/1_order/Laser_Cut_parts/sized/2mm_color_face2_size_x1.dwg
docs/1_order/Almite_parts/L_almite_braket_3mm_x2.ipt
docs/1_order/Almite_parts/LiDAR_LD19_LD_Plate_1mm_x1.ipt
docs/1_order/Almite_parts/head_T_braket_alminium_3mm_x2.ipt
docs/1_order/Almite_parts/hinge_stopper1_alminium_3mm_x4.ipt
docs/1_order/Almite_parts/hinge_stopper2_alminium_3mm_x4.ipt
docs/1_order/Laser_Cut_parts/sized/idw/1mm_clear_face1_size_x1.idw
docs/1_order/Laser_Cut_parts/sized/idw/2mm_color_face2_size_x1.idw
docs/1_order/Laser_Cut_parts/sized/idw/3mm_clear_display1_size_x1.idw
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

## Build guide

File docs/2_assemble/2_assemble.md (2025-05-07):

## 組み立て(Assemble)

<br>

**力が必要な部分があります。注意してください**

<br>
---

### 手順
---

##### [1.顔](./2-1.details/2-1.face.md)
顔を組み立てます

##### [2.アルミフレーム](./2-1.details/2-2.almi_frame.md)
アルミフレームを組み立てます

##### [3.キャスター](./2-1.details/2-3.caster.md)
キャスターをアルミフレームに取り付けます

##### [4.タイヤ](./2-1.details/2-4.tyya.md)
タイヤを作ります

##### [5.足回り](./2-1.details/2-5.undercarrige.md)
足回りのバネを作ります

##### [6.モーターコントローラの設定](./2-1.details/2-6.motor_controller.md)
モーターコントローラの設定をします

##### [7.センサ](./2-1.details/2-7.sensor.md)
センサをアルミフレームに取り付けます

##### [8.スピーカの配線](./2-1.details/2-8.speaker_connector.md)
スピーカをボディに取り付けます

---

**Pages**
[1.部品調達・発注(order)](../1_order/1_order.md)
[2.組み立て(assemble)](../2_assemble/2_assemble.md)
[3.PC設定(pc_setting)](../3_pc_setting/3_pc_setting.md)
[4.センサ設定(sensor_setting)](../4_sensor_setting/4_sensor_setting.md)
[5.モーター設定(motor_setting)](..//5_motor_setting/5_motor_setting.md)
[6.デバイステスト(device_test)](../6_device_test/6_device_test.md.md)
---

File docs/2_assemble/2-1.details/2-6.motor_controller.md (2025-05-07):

## モーターコントローラの配線

モーターコントローラの配線をします。

---

## 必要な工具

- はんだ
- ニッパー
- ワイヤーストリッパー
- ヒートガン

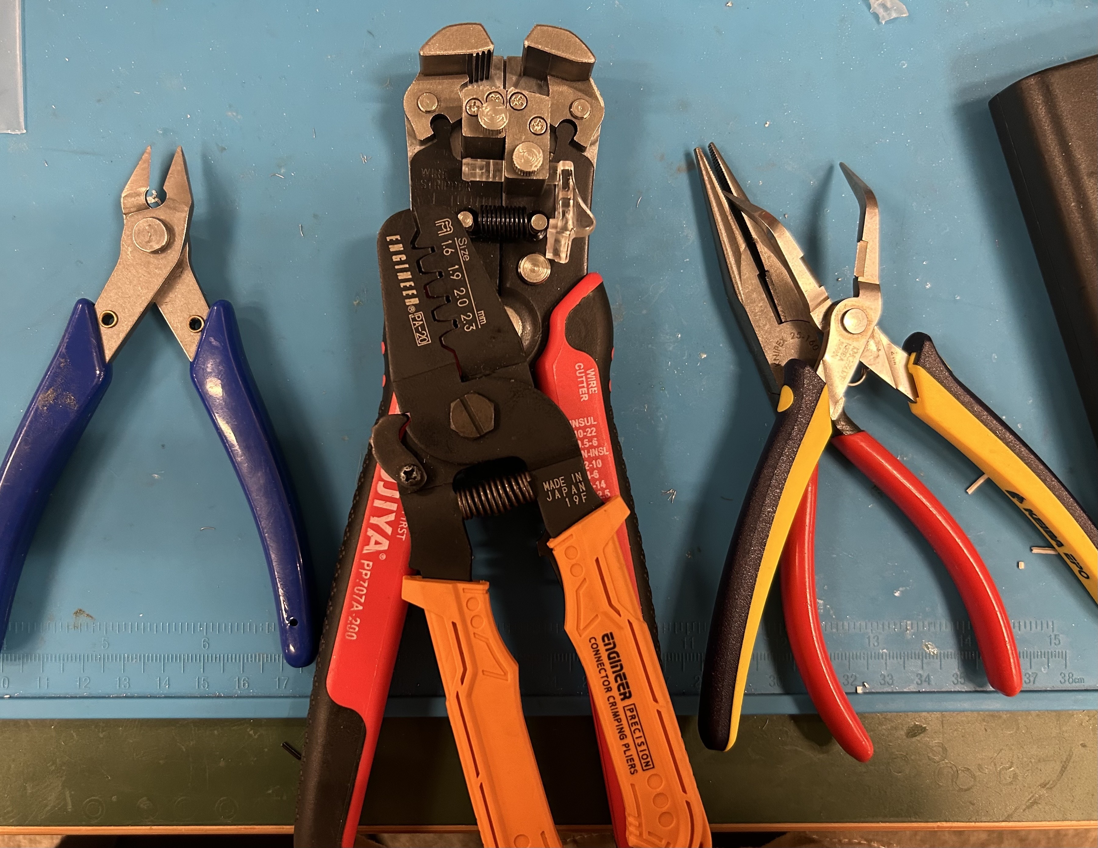
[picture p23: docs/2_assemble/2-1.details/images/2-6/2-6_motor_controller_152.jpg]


---

## 部材

- CANablePro(1個)

- Morex 3.25ピッチ電源コネクタ(基板L型 / 3pin /1個)
- Morex 3.25ピッチ電源コネクタ(ソケット / 3pin /1個)
- 5pinSMコネクタ(ソケット・コネクタ各1個)
- DC電源コネクタ(内径2.5mm)
- RoboMaster C610(x2)
- RoboMaster C610に付属の熱収縮チューブ(2本)
- 透明の熱収縮チューブ(Φ21)
- 赤の熱収縮チューブ(Φ6)
- 黒の熱収縮チューブ(Φ6)

- 赤, 緑, 黒のケーブル(AWG20　各1本)
- リボンケーブル
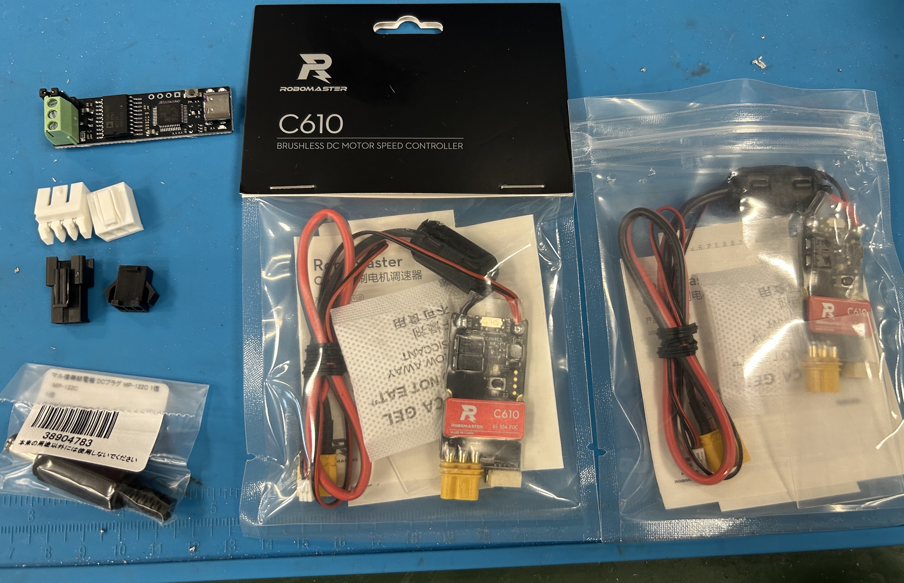
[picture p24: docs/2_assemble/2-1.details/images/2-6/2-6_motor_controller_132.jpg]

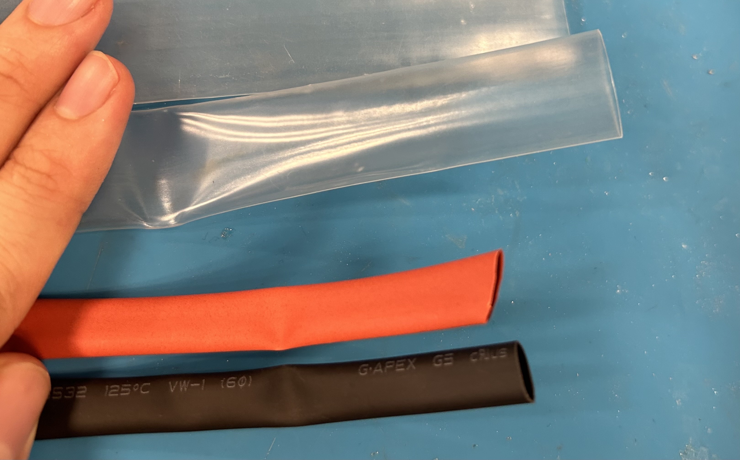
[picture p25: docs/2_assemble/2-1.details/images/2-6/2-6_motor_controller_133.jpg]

---

## 手順①ケーブル・熱収縮チューブのカット

赤黒緑のケーブルは120[mm]にカットする<br>
リボンケーブルは3芯だけむいて、120[mm]にカットしたものを2本つくる<br>
透明の熱収縮チューブは50[mm]にカット<br>
赤黒の熱収縮チューブは30[mm]にカット<br>

---

## 手順②CANableProのコネクタつけ
基板の裏を見てVer1.0か2.0か確認する<br>
Ver1.0の基板の方は右下のジャンパピンをTERMの方に切り替えます。<br>
3PINのコネクタを取り外します
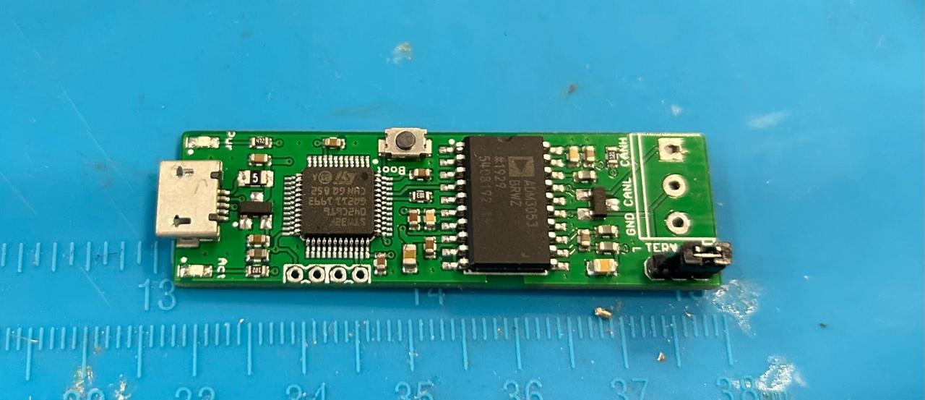
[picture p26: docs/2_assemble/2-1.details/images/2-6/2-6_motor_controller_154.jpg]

Morexの3Pinを取り付けます
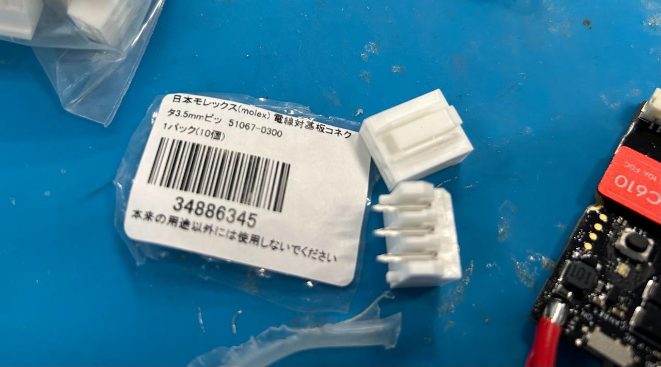
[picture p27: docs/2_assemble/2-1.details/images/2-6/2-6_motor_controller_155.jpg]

ここで基板のバージョンによってCANL, CANH, GNDの順が異なるので注意
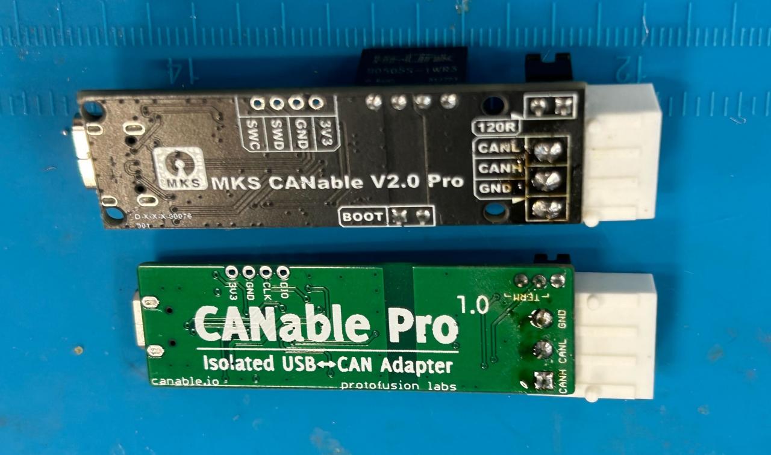
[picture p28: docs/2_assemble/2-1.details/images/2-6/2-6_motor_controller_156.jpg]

どれがどのピンか書いておくとわかりやすい
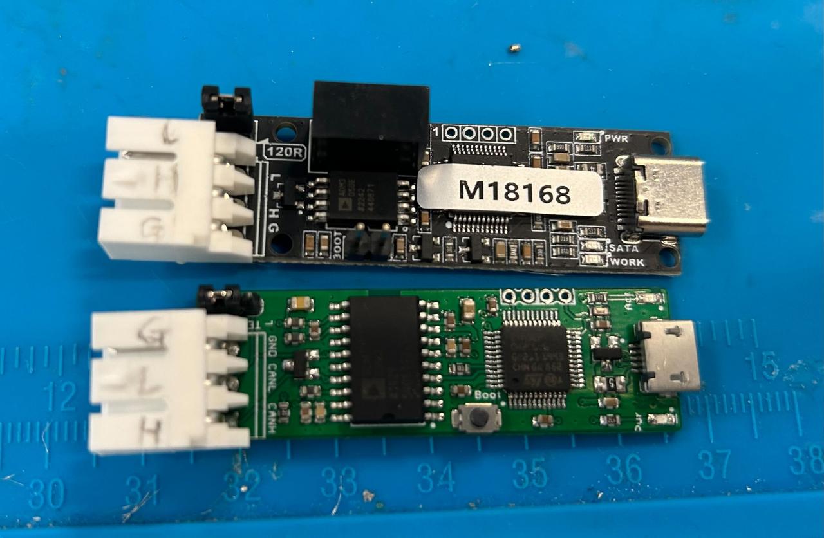
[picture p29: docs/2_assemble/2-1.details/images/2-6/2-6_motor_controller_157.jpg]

## 手順③CANableProとSMコネクタのケーブル作成
- 赤・黒・緑のケーブルを使ってケーブルを作成します<br>
- SMコネクタ<br>
　- 1番:GNDと黒ケーブルでつなぐ<br>
　- 2番:CANLと緑ケーブルでつなぐ<br>
　- 3番:CANHと赤ケーブルでつなぐ<br>

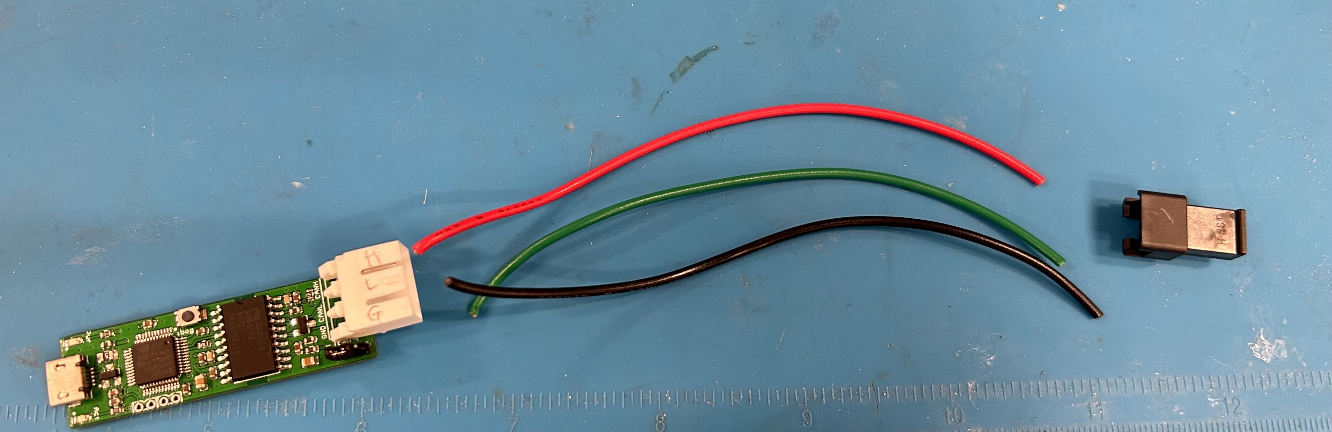
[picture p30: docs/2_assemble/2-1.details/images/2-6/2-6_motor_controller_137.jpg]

ワイヤーストリッパーで被膜をむく
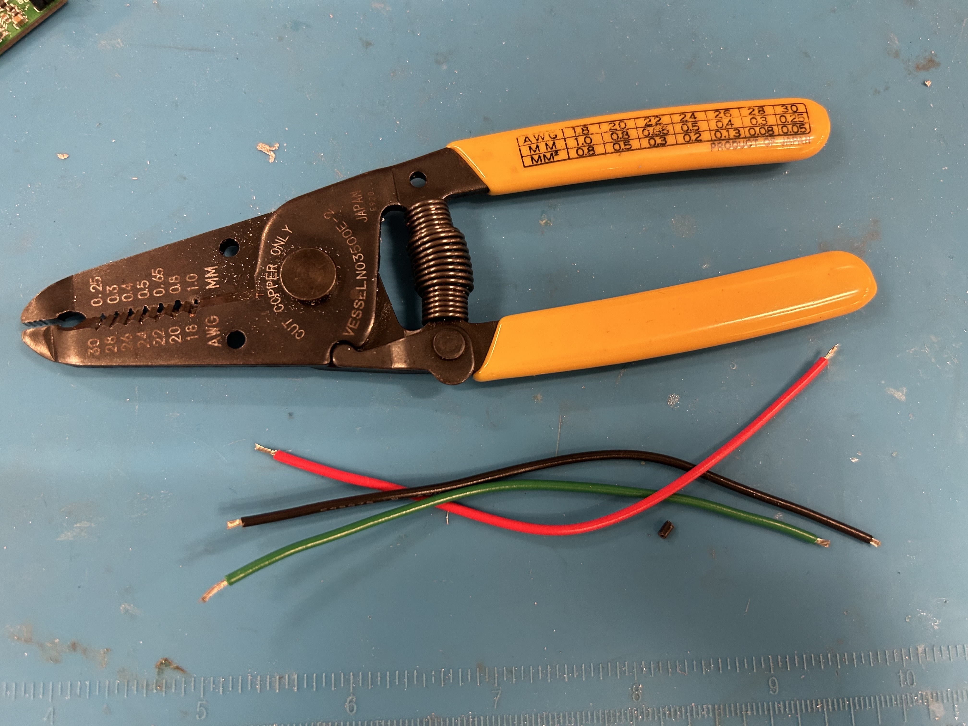
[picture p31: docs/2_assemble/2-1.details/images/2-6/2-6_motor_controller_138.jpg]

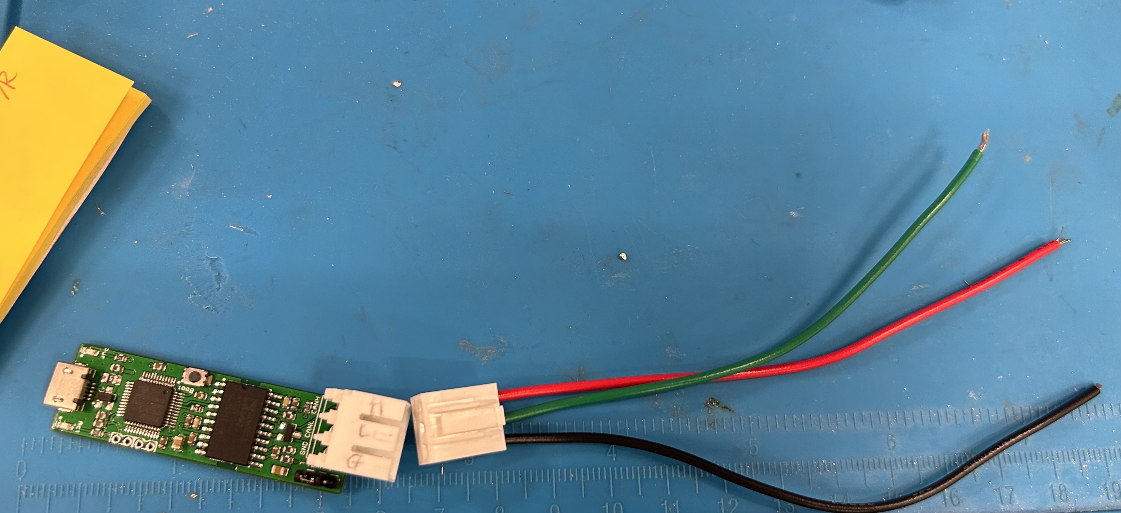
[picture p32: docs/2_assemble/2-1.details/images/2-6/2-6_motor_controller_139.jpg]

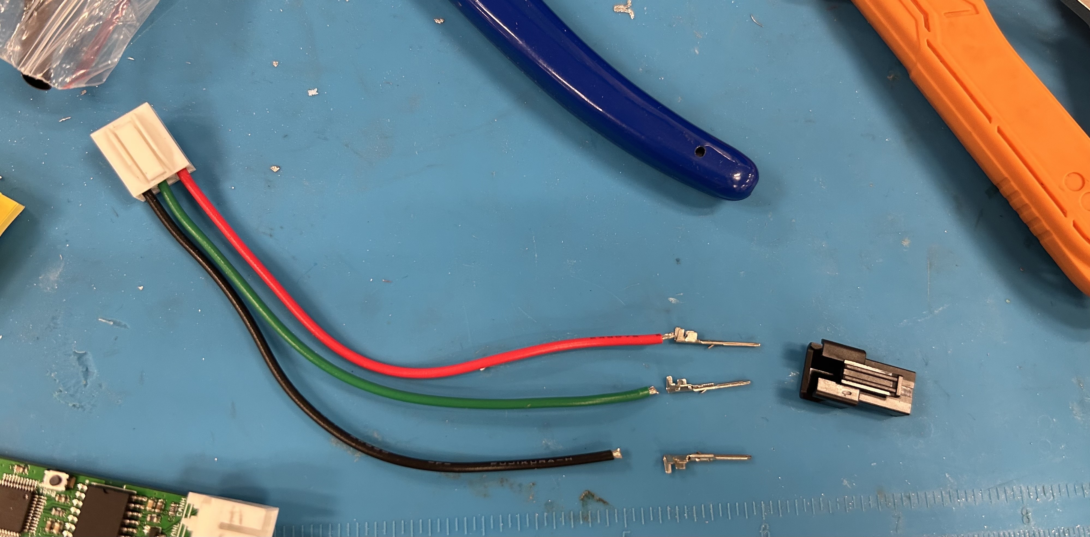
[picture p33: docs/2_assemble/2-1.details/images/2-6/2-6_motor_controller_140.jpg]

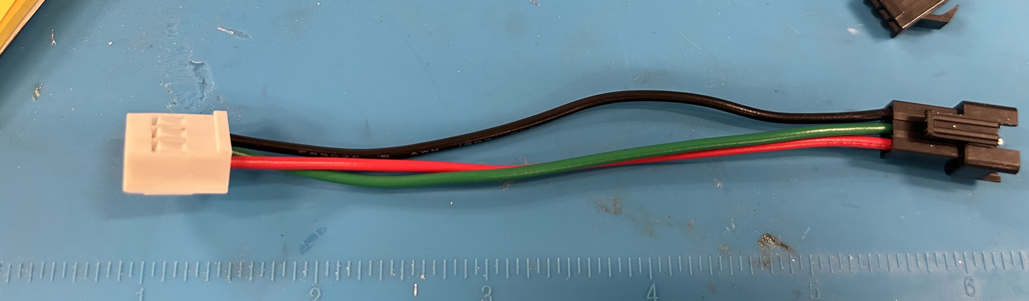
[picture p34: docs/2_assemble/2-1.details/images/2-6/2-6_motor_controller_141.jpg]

## 手順④モータコントローラの電源ケーブル作成
電源を120[mm]くらいのところでカットする<br>
細い線はいったんはんだをとっておく<br>
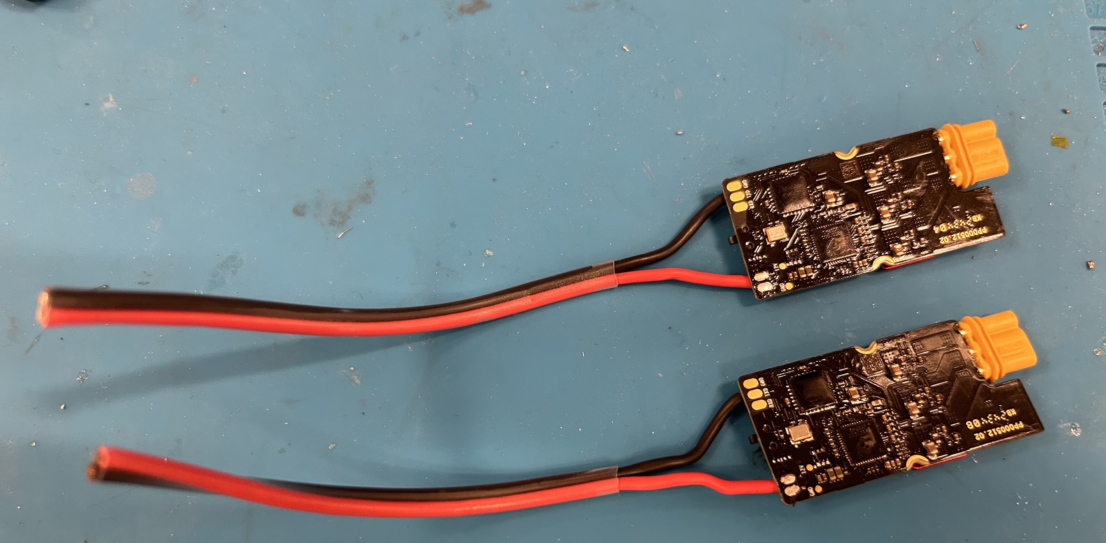
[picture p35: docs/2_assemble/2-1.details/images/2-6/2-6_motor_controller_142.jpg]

切った残りのケーブル1本と、モータコントローラにつながっている電源ケーブル2本<br>
切った残りのケーブル1本にΦ6の熱収縮チューブをいれておく<br>
合計3本×赤黒で6本の被膜を向いて電源とGNDそれぞれまとめてはんだづけ
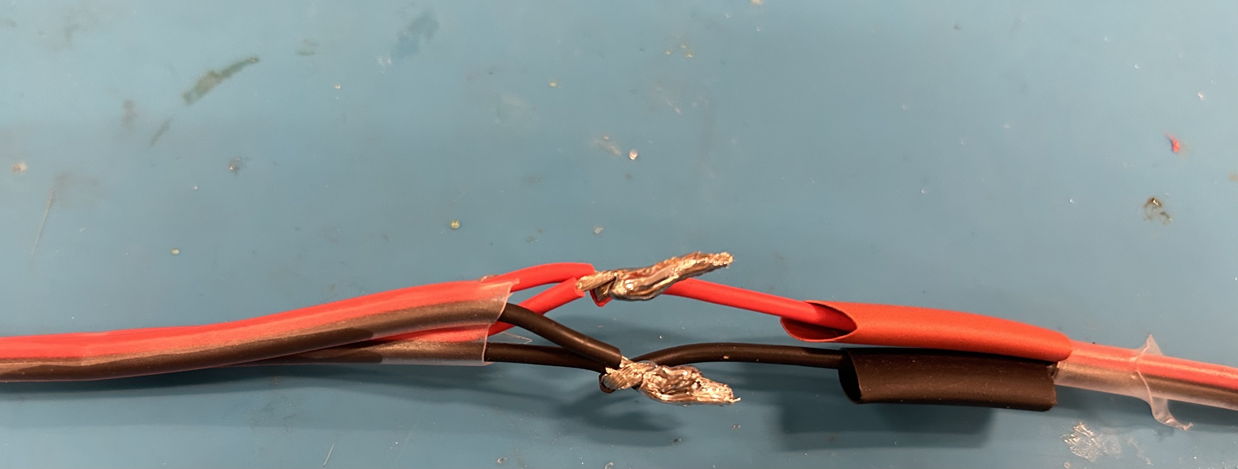
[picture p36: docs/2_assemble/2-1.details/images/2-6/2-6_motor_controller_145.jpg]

赤と黒の熱収縮チューブを熱収縮する。DCジャックのカバーを通す
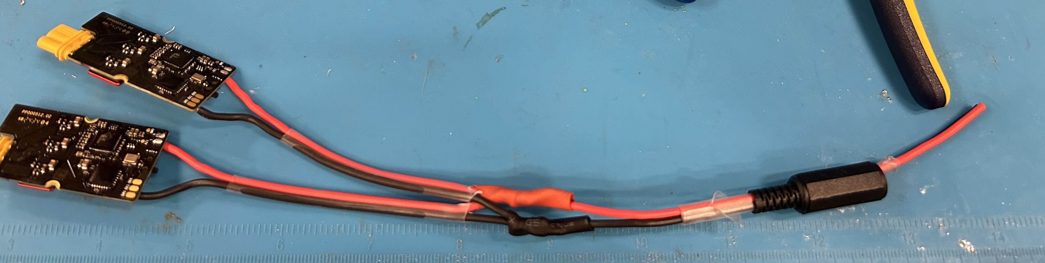
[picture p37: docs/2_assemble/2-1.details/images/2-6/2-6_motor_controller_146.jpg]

写真のようにケーブルをカットし、DCジャックにはんだ付け
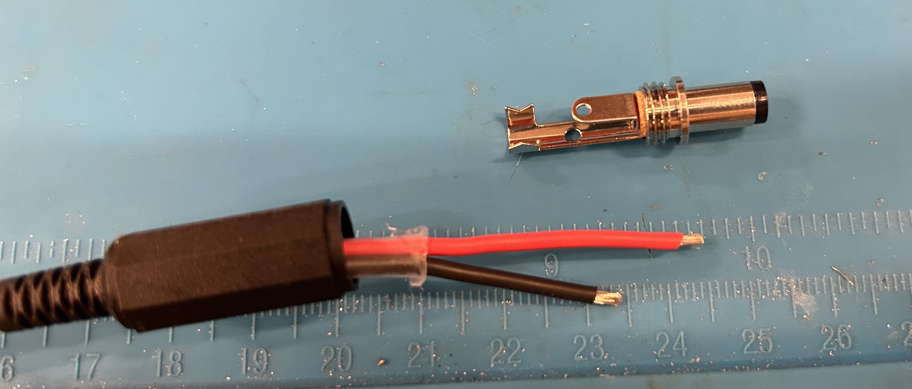
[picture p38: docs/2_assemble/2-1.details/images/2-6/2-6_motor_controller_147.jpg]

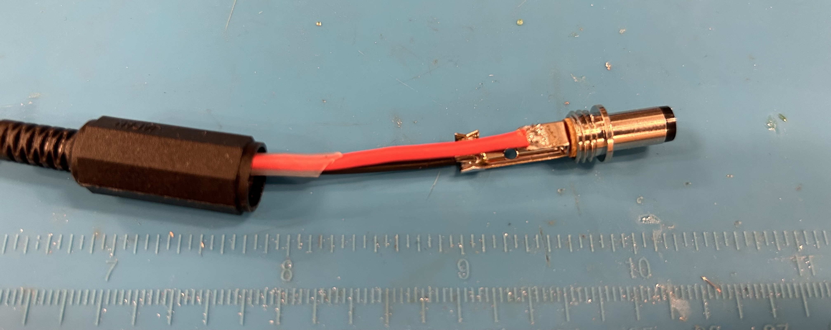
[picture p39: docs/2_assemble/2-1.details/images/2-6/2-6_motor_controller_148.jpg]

## 手順⑤モータコントローラのCANとSMコネクタのケーブル作成
CANL, CANH, GNDにリボンケーブルをはんだづけする
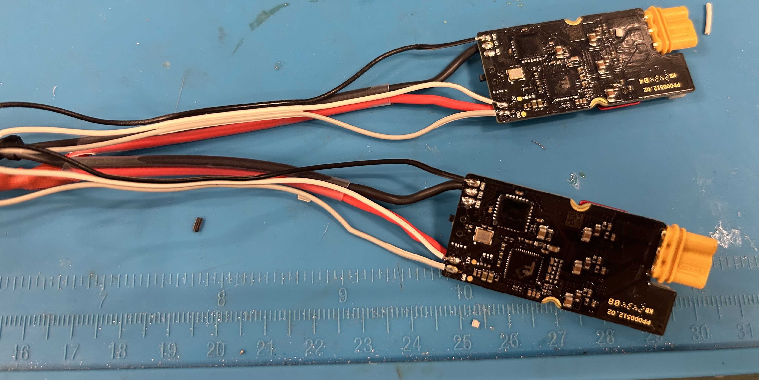
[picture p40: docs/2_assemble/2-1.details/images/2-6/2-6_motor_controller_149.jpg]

- SMコネクタ<br>
　- 1番:GNDとつなぐ<br>
　- 2番:CANLとつなぐ<br>
　- 3番:CANHとつなぐ<br>
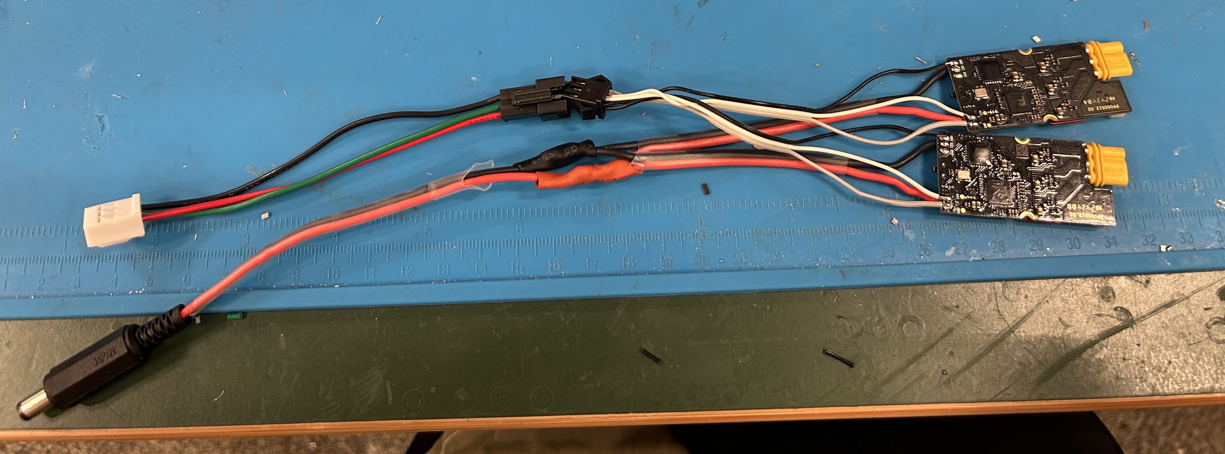
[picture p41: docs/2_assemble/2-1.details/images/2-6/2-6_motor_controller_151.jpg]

## 手順⑥熱収縮
テスターがあればCANH, CANL, GNDがつながっていることを確認する<br>
CANAbleProにΦ21の熱収縮チューブを取り付ける<br>
モーターコントローラに付属の熱収縮チューブをとりつける<br>

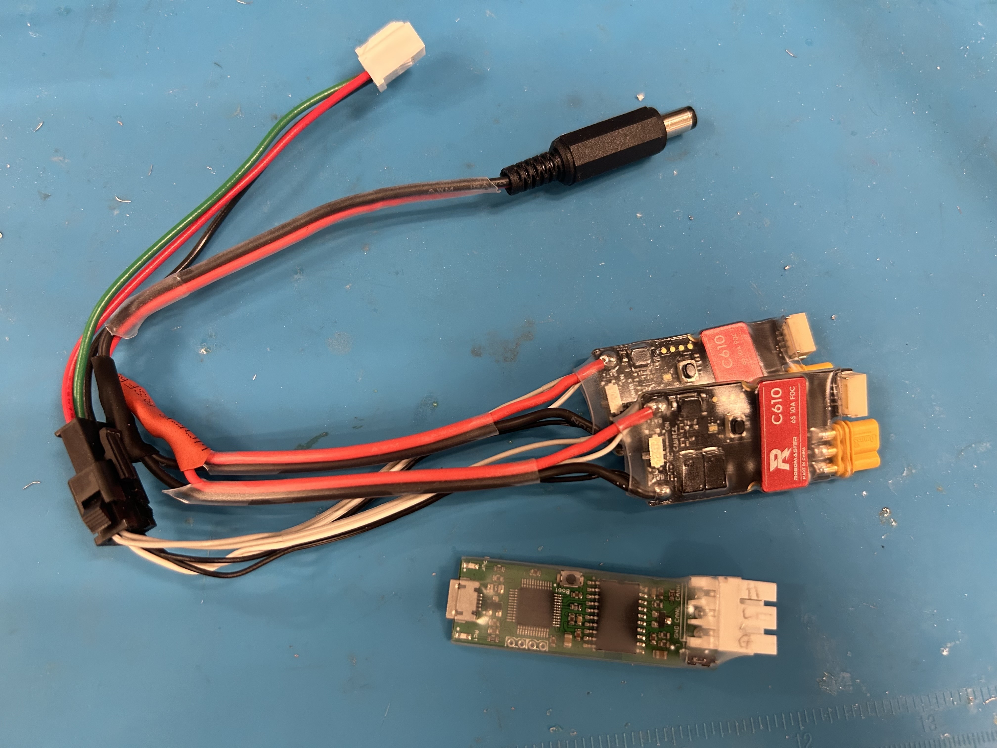
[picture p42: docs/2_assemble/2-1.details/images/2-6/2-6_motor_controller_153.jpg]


## 手順⑦テスト
**電源テスト**<br>
モータコントローラとモータを接続します。<br>
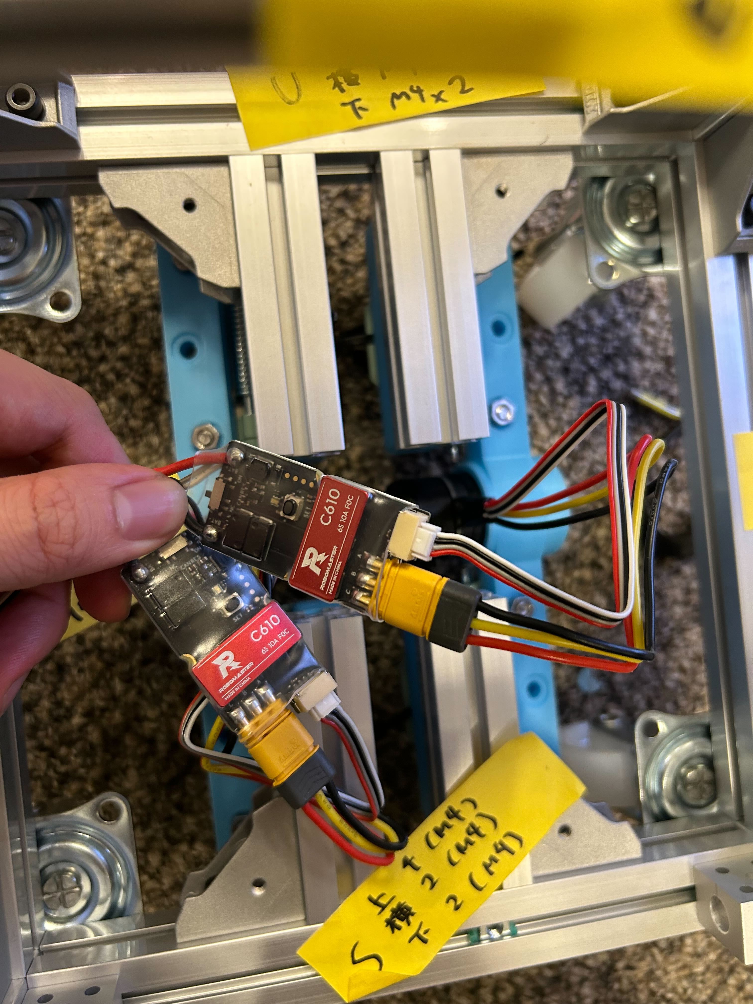
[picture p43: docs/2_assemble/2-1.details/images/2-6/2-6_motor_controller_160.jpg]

使用するモバイルバッテリ [SANWA](https://direct.sanwa.co.jp/ItemPage/700-BTL033BK)を12Vに設定します<br>
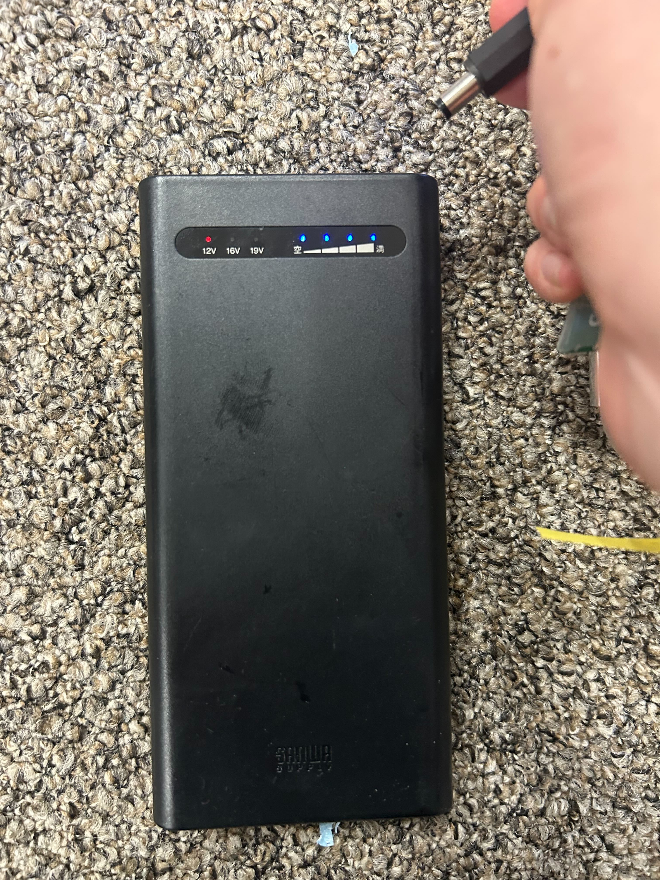
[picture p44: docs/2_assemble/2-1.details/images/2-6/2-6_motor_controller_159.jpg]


モータコントローラのDCジャックをモバイルバッテリのDC出力に接続します<br>
モータコントローラから音がなって、赤以外に点滅したら成功<br>

**ID設定**<br>
モータコントローラ(C610)の黒いボタンを1回押す(LEDは光らない)<br>
設定したいIDの回数分、ボタンを押します。<br>
2個使用するので、1個は1回、もう1個は2回押します。<br>
完了するとオレンジに1度光ります。<br>
成功すると音がなってLEDがIDの回数分だけ緑で光ります。<br>

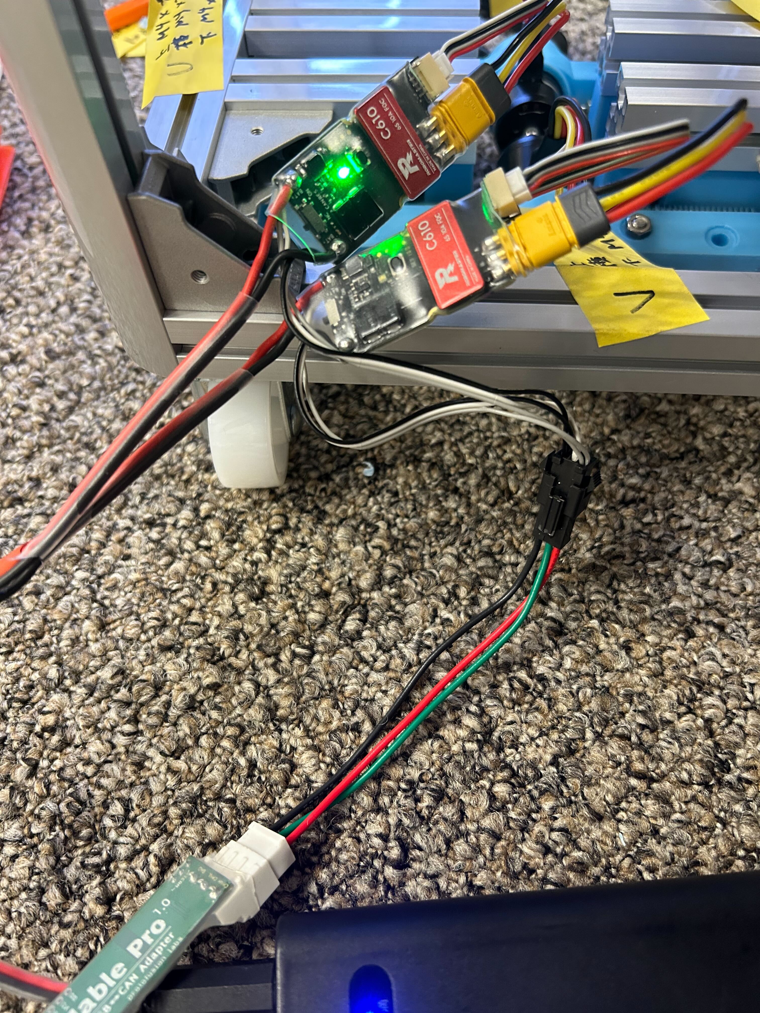
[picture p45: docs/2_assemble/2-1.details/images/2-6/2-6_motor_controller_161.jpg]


インシュロックでボディにコントローラを取り付けます<br>
ロボットの左モータがID1(緑が1回点滅する方)<br>
右モータがID2(緑が2回点滅する方)にします<br>

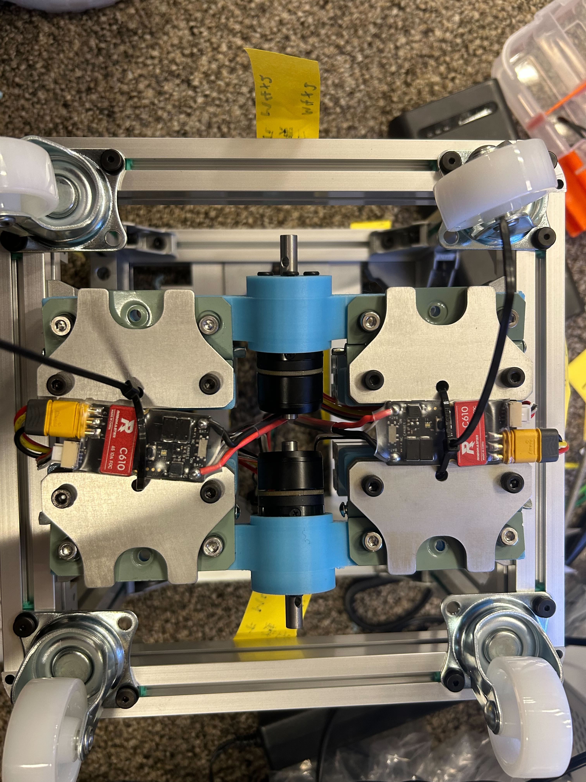
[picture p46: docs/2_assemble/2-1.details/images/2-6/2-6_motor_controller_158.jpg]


---
[indexに戻る](../../index.md)
|[assenbleに戻る](../2_assemble.md)
|[前のページ](./2-5.undercarrige.md)
|[次のページ](./2-7.sensor.md)

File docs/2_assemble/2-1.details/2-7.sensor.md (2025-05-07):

## センサーの取り付け

センサーを取り付けます

---

## 必要な工具

- 六角レンチ
- ヒートガン

---

## 部材
※AIカメラと深度カメラはM6ではなく本来1/4インチネジですが<br>
　M6でぎりぎり入るのでそうしてます。<br>

- LiDAR
- LiDAR取り付け用金属部材
- AIカメラ
- AIカメラ取り付け用3Dプリント部品
- RealsenseD435
- Realsense取り付け用3Dプリント部品
- 透明の熱収縮チューブ(Φ21) 40[mm]

- ネジ
　　- M2.5
        - 六角穴 / 黒 / 5[mm] (3本)
    - M4
        - 六角穴 / 黒 / 10[mm] (8本)
    - M6( or 1/4inchねじ)
        - 六角穴 / ステンレス /　8[mm] (1本):深度カメラ用
        - 六角穴 / 黒 /　5[mm] (1本):AIカメラ用
- ナット
    - M2.5(3個)

---

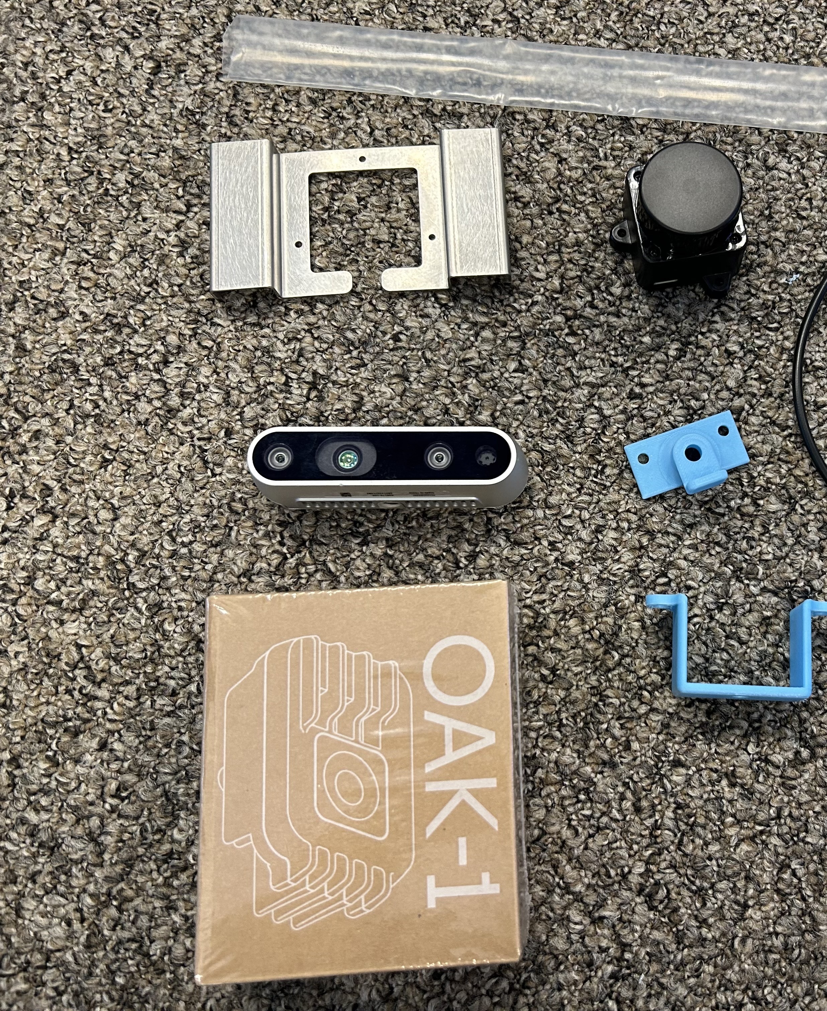
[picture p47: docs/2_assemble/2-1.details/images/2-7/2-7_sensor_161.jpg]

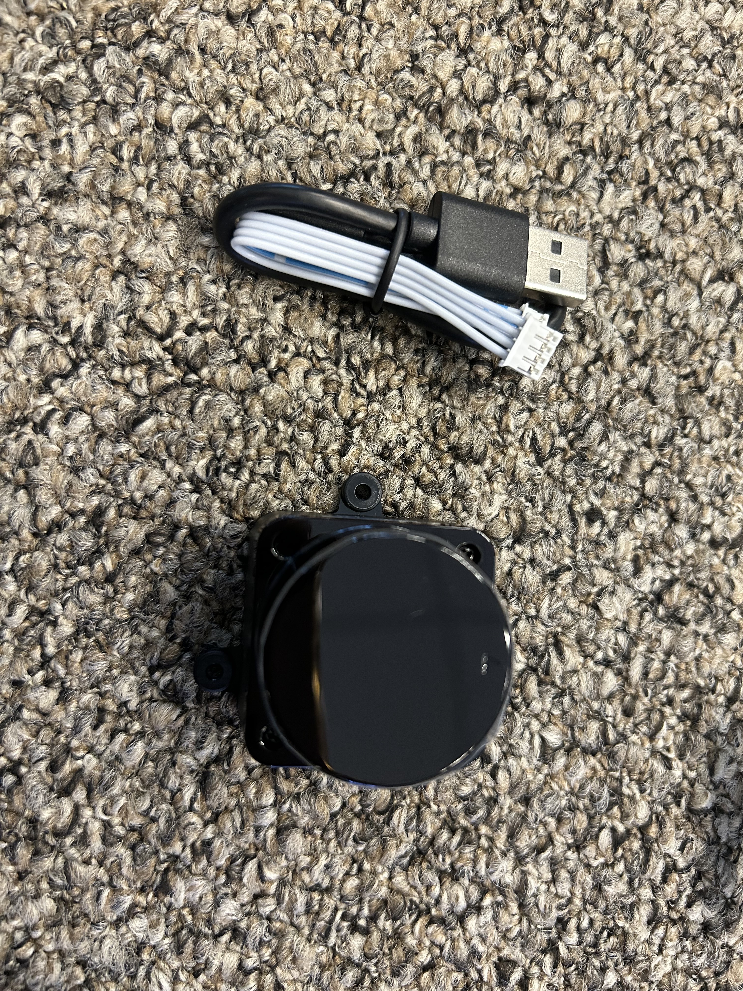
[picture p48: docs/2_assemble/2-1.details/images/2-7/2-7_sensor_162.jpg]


## 手順①取り付けパーツをつける
深度カメラに3Dパーツを下からM6のステンレスネジでつける<br>
AIカメラに3DパーツをM6の黒ネジでつける
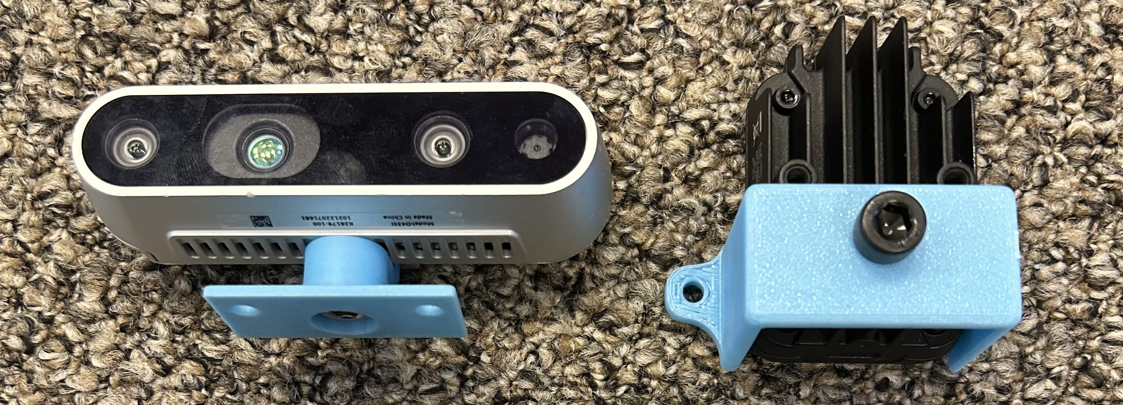
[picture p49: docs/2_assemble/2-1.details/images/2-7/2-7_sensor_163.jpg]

LiDARはM2.5ねじ3個とナットで図のようにつける
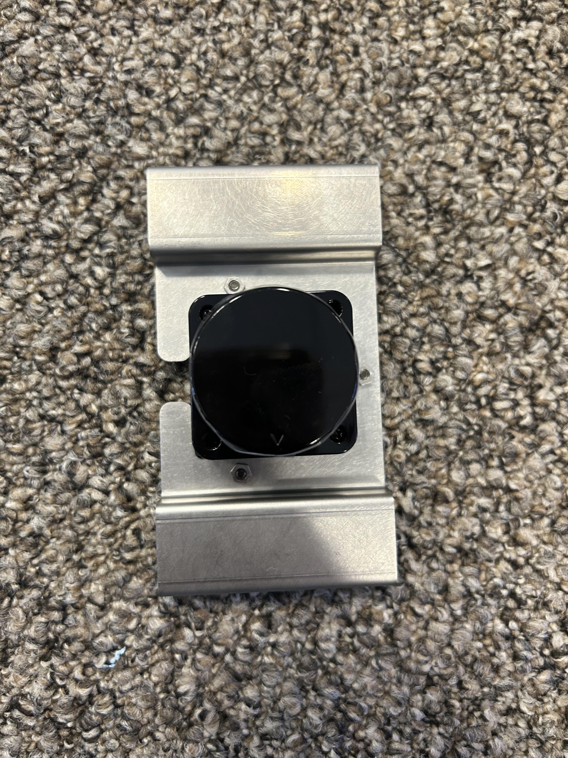
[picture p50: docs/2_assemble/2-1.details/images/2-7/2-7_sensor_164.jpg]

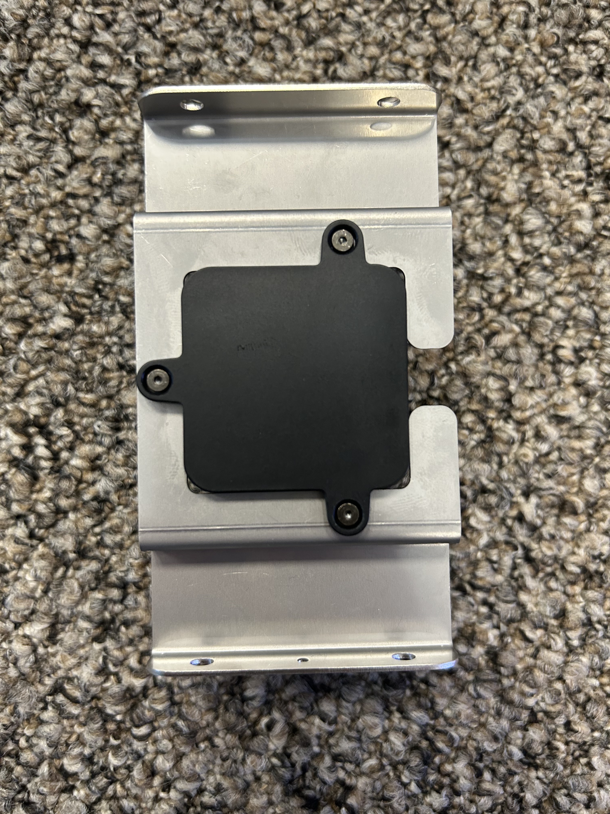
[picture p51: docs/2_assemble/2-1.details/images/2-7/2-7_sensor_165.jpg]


## 手順②本体への取り付け
前面に深度カメラ、上部にLiDAR、前面にAIカメラの順でとりつける
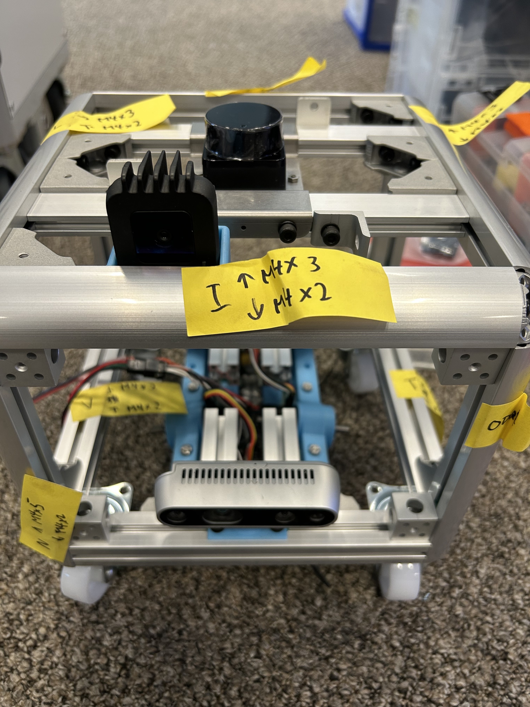
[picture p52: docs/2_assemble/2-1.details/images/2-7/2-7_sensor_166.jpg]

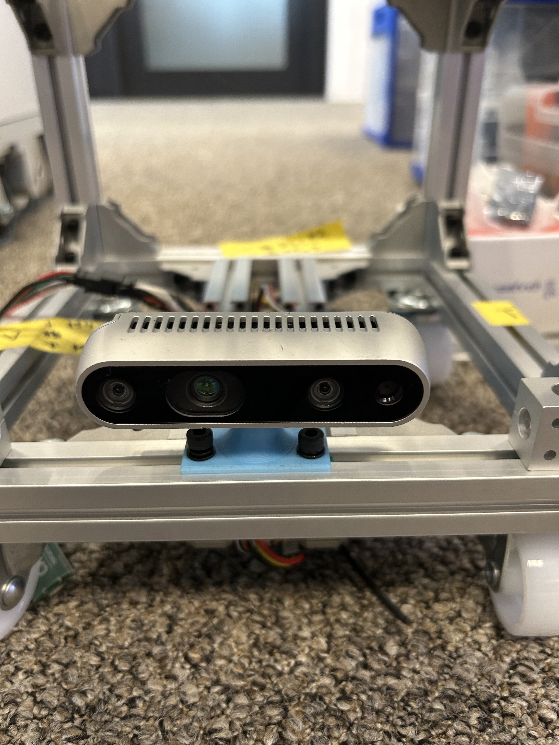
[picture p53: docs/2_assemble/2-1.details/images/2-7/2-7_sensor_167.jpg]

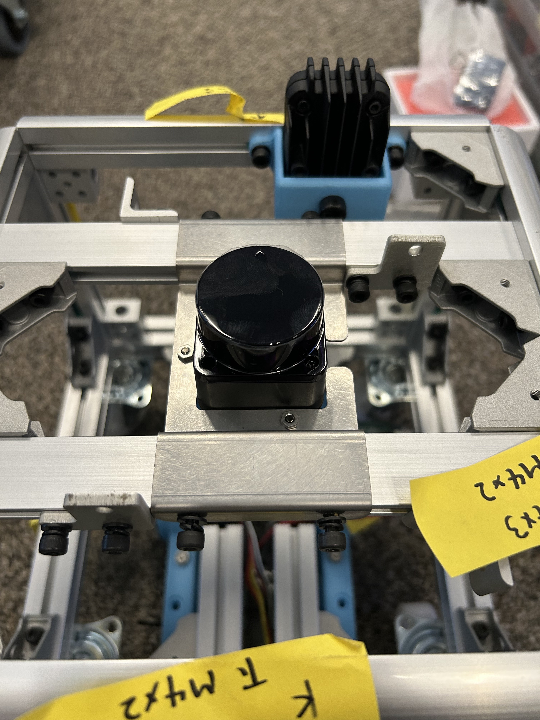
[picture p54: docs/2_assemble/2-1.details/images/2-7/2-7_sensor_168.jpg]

LiDARは小さな丸がついている方が前面で真ん中
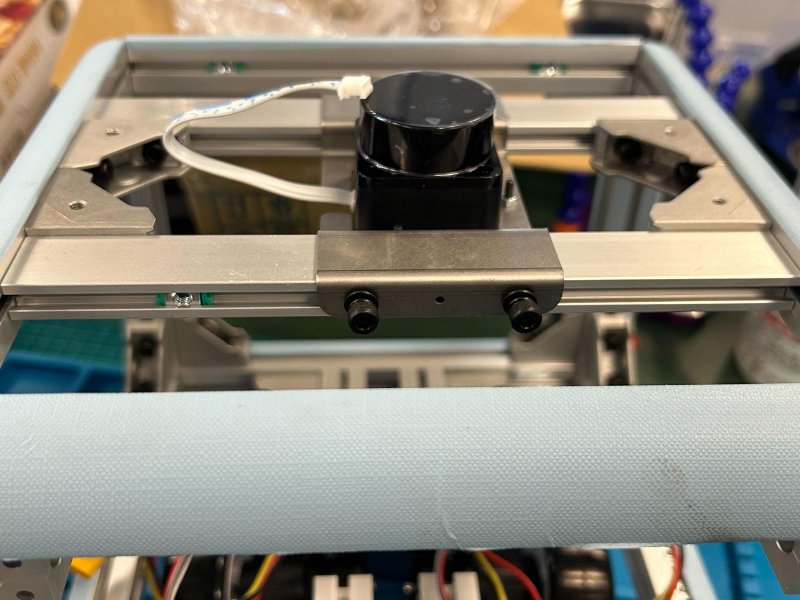
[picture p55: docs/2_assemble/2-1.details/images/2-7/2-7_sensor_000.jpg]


## 手順③LiDAR基板の熱収縮
40[mm]にカットした熱収縮チューブを取り付けて熱収縮する
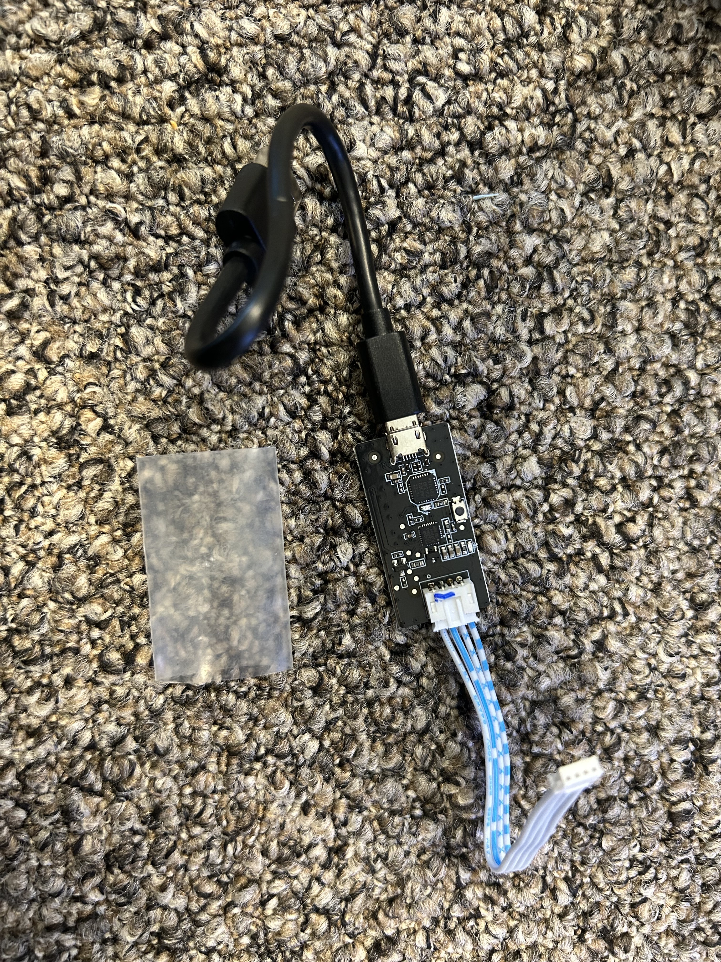
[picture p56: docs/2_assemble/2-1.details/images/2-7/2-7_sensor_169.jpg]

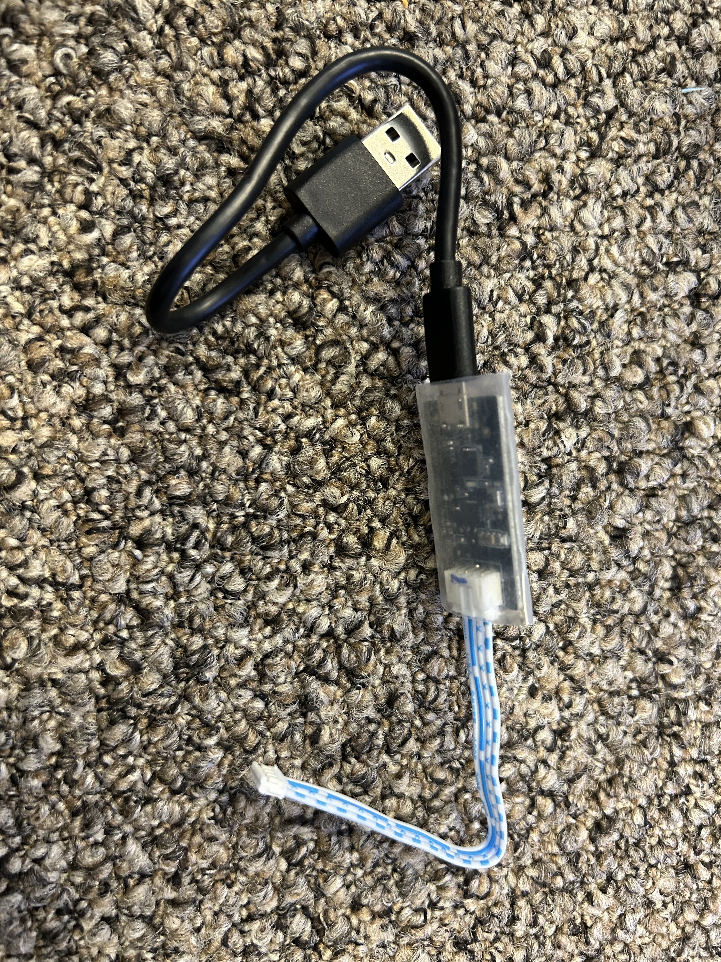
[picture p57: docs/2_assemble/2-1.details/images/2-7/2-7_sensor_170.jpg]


---
[indexに戻る](../../index.md)
|[assenbleに戻る](../2_assemble.md)
|[前のページ](./2-6.motor_controller.md)
|[次のページ](./2-8.speaker_connector.md)

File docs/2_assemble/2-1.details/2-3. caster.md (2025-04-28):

## キャスターの取り付け

キャスターを取り付けます

---

## 必要な工具

- 六角レンチ

---

## 部材

- キャスター4個
- ネジ
    - M4(黒、極低頭、滑り止め付き)
        - 10[mm]　(12個)
- M4ワッシャー(12個)
- M4スプリングワッシャー(12個)

---

## 手順①取り付け
低頭ねじにスプリングワッシャー・ワッシャーの順でとりつけます
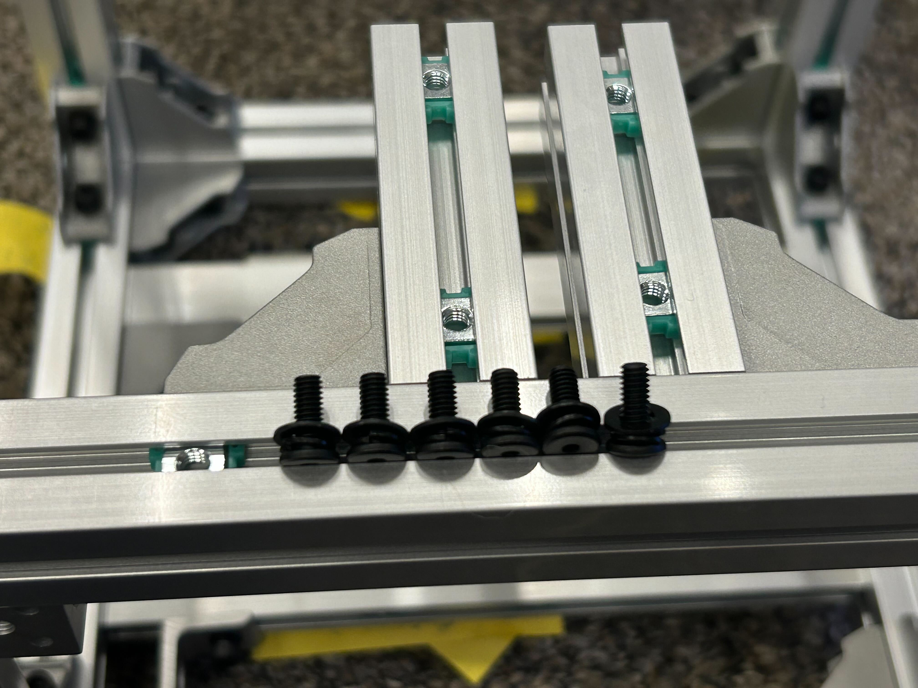
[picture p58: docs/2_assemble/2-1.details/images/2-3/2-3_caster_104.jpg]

キャスターの向きに注意して、3点ずつ止めます
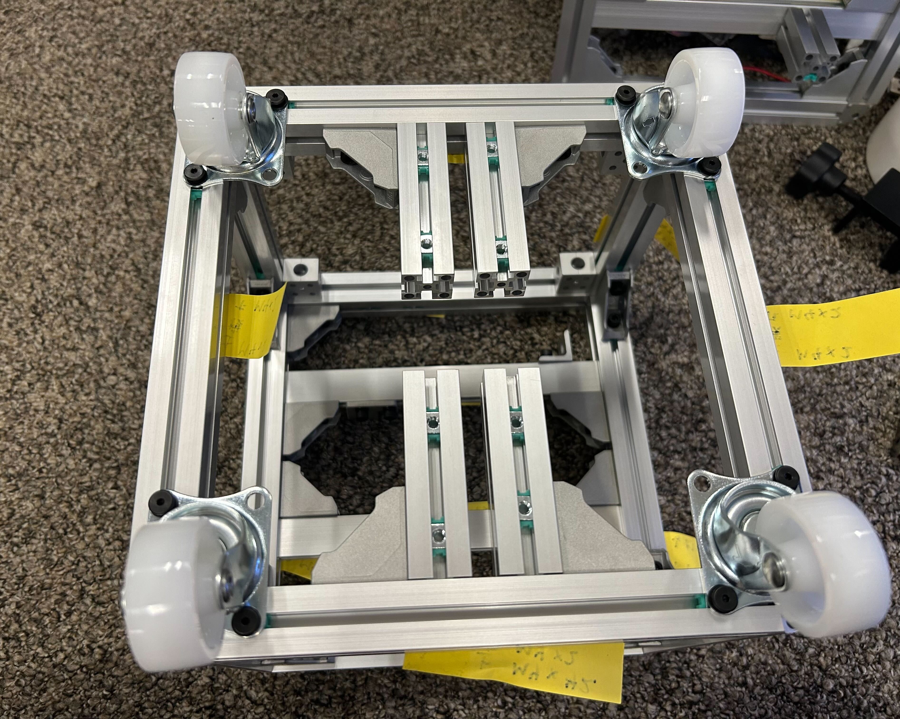
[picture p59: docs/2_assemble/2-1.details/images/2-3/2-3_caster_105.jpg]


---
[indexに戻る](../index.md)
|[assenbleに戻る](../2_assemble.md)
|[次のページ](./2-4.sensor.md)

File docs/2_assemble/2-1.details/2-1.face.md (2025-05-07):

## 顔の組み立て
<br>
ディスプレイをアクリル板にはめて顔を組み立てます。
<br>

---
## 工具

- ニッパー
- 六角レンチ

## 必要な部品

- ネジ
    - M4(SSHS)
        - 10[mm] (2本)
        - 16[mm] (2本)
    - M2.5(黒)
        - 6[mm] (2本)　
- ナット
    - M4(6個)
    - M2.5(2個)
- アクリル板
    - face1 透明1mm (1枚)
    - face2 カラー2mm (1枚)
    - display1 透明3mm (1枚)
    - displau2 透明3mm (1枚)

## 手順①ディスプレイの取り付け
ディスプレイの下2つのタブをニッパーでカットする
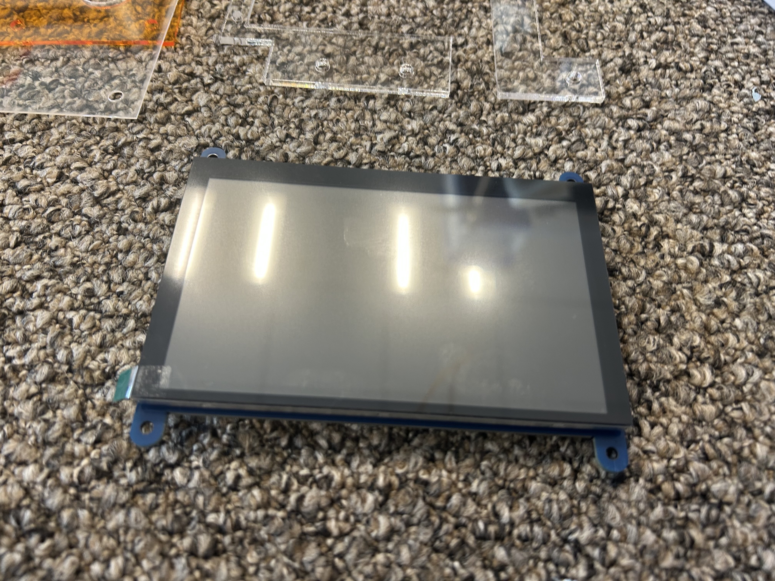
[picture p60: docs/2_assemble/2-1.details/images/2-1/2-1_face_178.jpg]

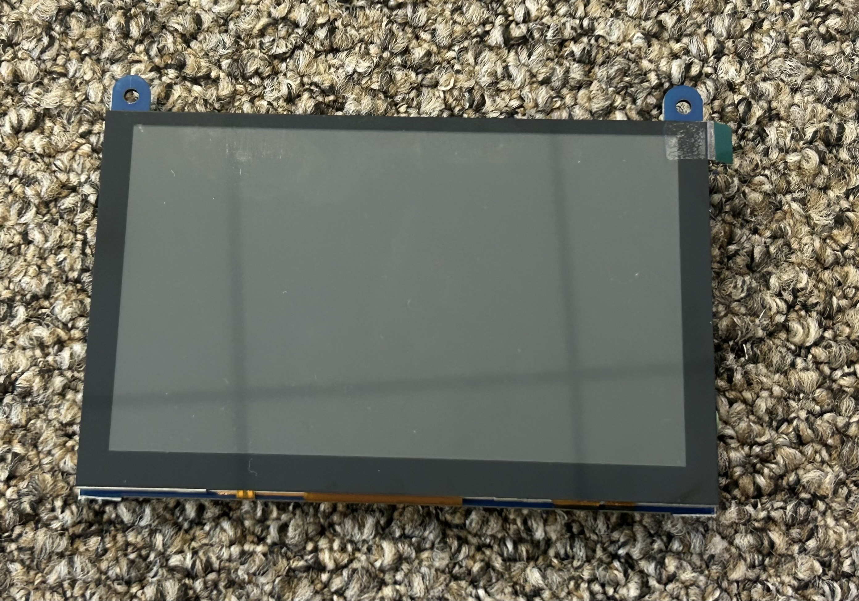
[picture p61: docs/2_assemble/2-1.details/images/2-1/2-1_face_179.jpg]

透明のアクリルをはさんでM2.5のねじ2つでとめる
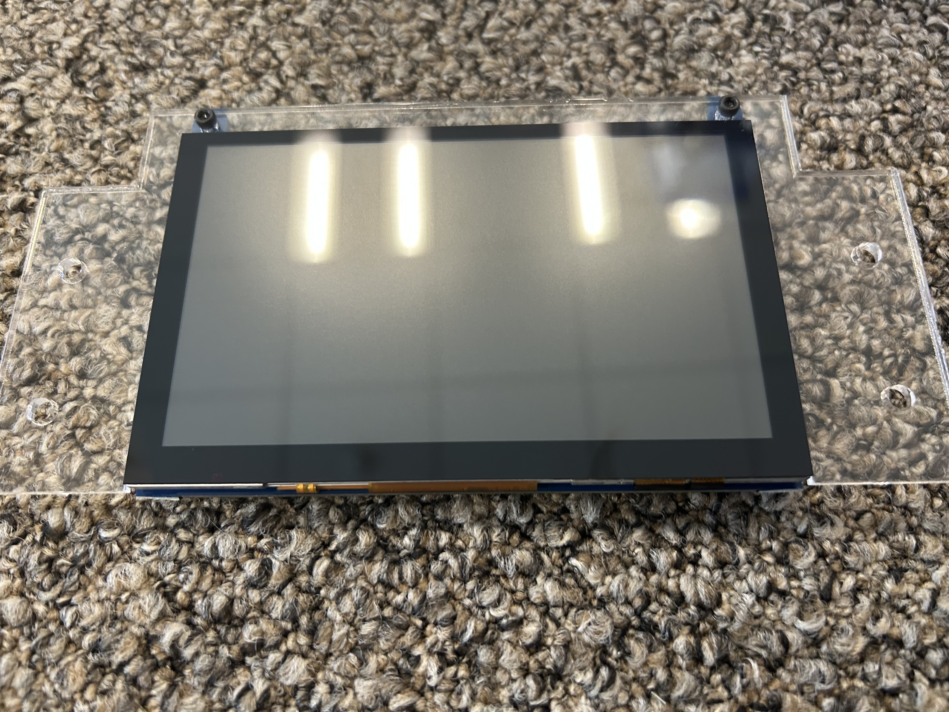
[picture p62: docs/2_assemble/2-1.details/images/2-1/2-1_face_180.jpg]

裏返して、下から透明1[mm]の板、色付きの板、ディスプレイと重ねる<br>
上から2番目の左右の穴にM4の10[mm]のねじ、その下に16[mm]のねじをナットで止める<br>

さらに透明の長細い板を取り付けて下にナットで止める

表に返して完成


---
[indexに戻る](../../index.md)
|[assenbleに戻る](../2_assemble.md)
|[次のページ](./2-2.almi_frame.md)

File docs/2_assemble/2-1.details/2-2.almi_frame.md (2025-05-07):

## アルミフレームの組み立て

ボディを作ります。

---

## 必要な工具

- 六角レンチ

---

## 部材

- アルミフレーム (26本)
- 三角ブラケット　(30個)
- 四角ブラケット (4個)
- 丸型ブラケット (8個)
- ネジ
    - M4(六角穴付ボルト(SCM435/黒色酸化皮膜) 全ねじ、滑り止め付き)
        - 10[mm]　(74個)
    - M4(ステンレス、全ねじ)
        - 8[mm] (8個)
- M4四角ナット (106個)
- ナットホルダー (106個)
- L字ブラケット(金属板加工品) (2個)
- T字ブラケット(金属板加工品)　(2個)
- L字ブラケット(Misumi) (2個)
---

## 手順①アルミフレームにナットホルダー＋ナットを取り付ける
頭から足までA-Zのアルミフレーム26本を用意します。<br>
ナットホルダーとナットを下の個数に合わせて取り付けます<br>

**Rのついた180[mm]のフレーム4本(ABCD)**<br>
A,C:片面にM4ナット2個<br>
B,D:片面にM4ナット4個<br>
(ナット12個)<br>

**薄い180[mm]のフレーム2本(EF)**<br>
E,F:片面M4ナット片面2個: 合計4個<br>
(ナット8個:総計20個)<br>

**四角い45[mm]のフレーム2本(EF)**<br>
G:同じ面にM4ナット2個<br>
H:対面にM4ナット各1個 合計2個<br>
(ナット4個:総計24個)<br>

**Rのついた180[mm]のフレーム4本(IJKL)**<br>
I,J,L:片面にM4ナット3個,片面にM4ナット1個、合計5個
K:片面にM4ナット1個、片面に2個、合計3個<br>
(ナット18個:総計42個)<br>

**薄い180[mm]のフレーム2本(MN)**<br>
M:M4ナットを片面3,片面4個、合計7個<br>
N:M4ナットを片面2,片面5個、合計7個<br>
(ナット14個:総計56個)<br>

**Rのついた150[mm]のフレーム4本(OPQR)**<br>
O,P,Q,R:M4ナットを各面に2個ずつ,合計4個<br>
(ナット16個:総計72個)<br>

**四角い180[mm]のフレーム4本(STUV)**<br>
S:上面にM4ナットを4個、後ろ面にM4ナットを2個、下面にM4ナットを2個、合計8個<br>
T:上面にM4ナットを2個、下面にM4ナットを2個、合計4個<br>
U:上面にM4ナットを2個、後ろ面にM4ナットを2個、下面にM4ナットを2個、合計6個<br>
V:上面にM4ナットを2個、下面にM4ナットを2個、合計4個<br>
(ナット22個:総計94個)<br>

**四角い70[mm]のフレーム4本(WXYZ)**<br>
W,Y:片面にM4ナット2個、90度傾けてM4ナット1個、合計3個<br>
X,Z:片面にM4ナット2個、90度反対に傾けてM4ナット1個、合計3個<br>
(ナット12個:総計106個)<br>
---

## 手順②天板の作成
仮組みなのでゆるくねじを締めてください。<br>
三角ブラケットの表面の穴がある方が外装側になります。向き注意<br>
**必要なもの**<br>
- 黒ねじ×16個<br>
- アルミフレーム(ABCD, EF)<br>
- 三角ブラケット(8個)<br>
- 丸形ブラケット(4個)<br>
- T字ブラケット(2個)<br>
①A,B,C,Dを時計回りに、EとFも三角ブラケットでつなげます(黄色レンチ)<br>


②角は丸形ブラケットを付属のネジ2本でつなげます(黄緑色レンチ)<br>
　残りの一本はとっておいてください<br>



## 手順③天板のつなぎフレームの作成
**必要なもの**<br>
- 黒ねじ×6個<br>
- アルミフレーム(G,H)<br>
- T字ブラケット(2個)<br>
①Eの前面にGをT字ブラケットでつなげます<br>
　Fの後面にHをT字ブラケットでつなげます<br>


※このパーツはとりあえず完成です。あとはセンサー類を取り付けてから組み立てます。<br>

## 手順④上面の作成
- 黒ねじ×18個<br>
- アルミフレーム(IJKLD, MN)<br>
- 三角ブラケット(6個)<br>
- L字ブラケット(2個)<br>
- L字金属板(2個)<br>
- 丸形ブラケット(4個)<br>
同じよう三角ブラケットでつなげます。<br>
写真のようにM,NにL字ブラケットとL字板を取り付けてください。

後面からみた写真

四隅に丸形ブラケットを取り付けます。

## 手順⑤底面の作成
**必要なもの**<br>
- 黒ねじ×8個<br>
- アルミフレーム(STUV, WXYZ)<br>
- 三角ブラケット(4個)<br>
図のように三角ブラケットをとりつけます。<br>
このとき、UとSフレームの中心に印をつけて、70mmフレームが左右対称に取り付けれるようにします。<br>




## 手順⑥上面と底面をつなげる
**必要なもの**<br>
- 黒ねじ×24個<br>
- ステンレスネジ(8個)<br>
- アルミフレーム(OPQR)<br>
- 三角ブラケット(12個)<br>
- 四角ブラケット(4個)<br>

左からOPQRです。図のように参画ブラケットを取り付けます。


作成した底面に図のように取り付けます。


作成した上面に図のように取り付けます。

ここで、Sフレームを残りのボディに取り付けます。<br>
四角ブラケットはネジ穴がある方が外装側になるようにします。<br>

大きな穴からステンレスネジを通します。

この形でボディの全面にとりつけます。




組み立て終わったら、位置を合わせてネジを固めに締めていきます。<br>
ひとまず完成です。センサを取り付けてから天板とボディをとりつけます。<br>

---
[indexに戻る](../../index.md)
|[assenbleに戻る](../2_assemble.md)
|[前のページ](./2-1.face.md)
|[次のページ](./2-3.caster.md)

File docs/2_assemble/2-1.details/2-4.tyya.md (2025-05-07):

## タイヤの制作

タイヤを制作します

---

## 必要な工具

- 瞬間接着剤
---
## 部材

- ホイール(2個)
- タイヤ(2個)
- インナースポンジ((2個))

---

## 手順①タイヤにインナースポンジをはめる


## 手順②タイヤにホイールをはめる


## 手順③瞬間接着剤を流す


完成

---
[indexに戻る](../../index.md)
|[assenbleに戻る](../2_assemble.md)
|[前のページ](./2-3.caster.md)
|[次のページ](./2-5.undercarrige.md)

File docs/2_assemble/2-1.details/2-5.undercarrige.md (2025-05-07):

## 足回りの組み立て

足回りの組み立てをします。

---

## 必要な工具

- 六角レンチ
- 大きなペンチ
---

## 部材

- 蝶番4つ
- 蝶番取り付け用3Dプリンタ部品4つ
- モータ取り付け用3Dプリンタ部品2つ
- モータ2つ
- ネジ
    - M4
       - 六角穴 / 全ねじ / ステンレス / 16[mm]x8[個]
        -  六角穴 / 半ねじ / 黒 / 35[mm]x8[個]
    - M3
        - 六角穴付き極低頭 / 全ねじ / 黒 / 8[mm]x6[本]
- M4ナット
    - 8個
- M4スプリングワッシャー
    - 8個
- インシュロック(4本)




---

## 手順①モータに3Dパーツを取り付ける
写真のように向きに注意してM3ネジを３つずつ取り付ける。<br>




## 手順②蝶番の2つのねじをきる
怪我に注意して、写真のように4つのうち2つの蝶番のネジをきる<br>


## 手順③モータパーツに蝶番を取り付ける
ばねを切った方の蝶番を写真のように取り付ける<br>
ねじはM4ステンレスとスプリングワッシャーを用いる<br>
蝶番の軸が奥に行くようにする

3Dパーツのくぼみに蝶番のネジが収まるようになっている<br>

両方取り付けた写真

ばねを切っていない方の蝶番も同じように取り付ける




## 手順④ボディに足回りパーツを取り付ける
まずはアルミフレームとナットの位置合わせから<br>
70[mm]アルミフレームは15.7[mm]ていどの距離を開けて左右対称にする<br>

ばねを切った方に、写真のように金属パーツ2枚とインシュロックを通す<br>
まずボディの後ろ側にとりつける<br>
インシュロックの向きに注意して直方体の3Dパーツとネジ止めする。<br>
ネジはM4黒の35[mm]



両方つけ終わった。

インシュロックを合体させる

ボディ前面側も同じように取り付ける<br>
35[mm]ねじに金属パーツ二種、インシュロック、ばね蝶番、3Dパーツの順でネジ止めをする

硬いので怪我に注意

インシュロックを取り付けて完成


タイヤは2-6のモータコントローラが終わってから取り付ける

---
[indexに戻る](../../index.md)
|[assenbleに戻る](../2_assemble.md)
|[前のページ](./2-4.tyya.md)
|[次のページ](./2-6.motor_controller.md)

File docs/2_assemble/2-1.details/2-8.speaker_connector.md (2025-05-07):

## スピーカのとりつけ

スピーカをとりつけます

---

## 必要な工具

- はんだ
- ワイヤーストリッパー
- 圧着工具
- ニッパー

---

## 部材

- speaker x2
- アンプ
- SMコネクタ 2pin 2セット



## 手順
アンプのケーブルを半分くらいにカットし、SMコネクタを取り付ける<br>
残りのケーブルで写真のようなケーブルを2本作成する<br>
片方はスピーカにはんだ付け、片方はSMコネクタをとりつける<br>
SMコネクタは黒色が1番になるようにする


スピーカにはんだ付けする(+が赤または白で、−が黒になるようにする)

写真のようにL字ブラケットを引っ掛けてとりつける

スピーカまでとりつけたら天板もとりつけて位置を調整しねじを固くしめる


---
[indexに戻る](../../index.md)
|[assenbleに戻る](../2_assemble.md)
|[前のページ](./2-7.sensor.md)
|[次のページ](../../3_pc_setting/3_pc_setting.md)

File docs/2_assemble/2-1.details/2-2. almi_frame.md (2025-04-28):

## アルミフレームの組み立て

ボディを作ります。

---

## 必要な工具

- 六角レンチ

---

## 部材

- アルミフレーム (26本)
- 三角ブラケット　(30個)
- 四角ブラケット (4個)
- 丸型ブラケット (8個)
- ネジ
    - M4(六角穴付ボルト(SCM435/黒色酸化皮膜) 全ねじ、滑り止め付き)
        - 10[mm]　(74個)
    - M4(ステンレス、全ねじ)
        - 8[mm] (8個)
- M4四角ナット (106個)
- ナットホルダー (106個)
- L字ブラケット(金属板加工品) (2個)
- T字ブラケット(金属板加工品)　(2個)
- L字ブラケット(Misumi) (2個)
---

## 手順①アルミフレームにナットホルダー＋ナットを取り付ける
頭から足までA-Zのアルミフレーム26本を用意します。<br>
ナットホルダーとナットを下の個数に合わせて取り付けます<br>

**Rのついた180[mm]のフレーム4本(ABCD)**<br>
A,C:片面にM4ナット2個<br>
B,D:片面にM4ナット4個<br>
(ナット12個)<br>

**薄い180[mm]のフレーム2本(EF)**<br>
E,F:片面M4ナット片面2個: 合計4個<br>
(ナット8個:総計20個)<br>

**四角い45[mm]のフレーム2本(EF)**<br>
G:同じ面にM4ナット2個<br>
H:対面にM4ナット各1個 合計2個<br>
(ナット4個:総計24個)<br>

**Rのついた180[mm]のフレーム4本(IJKL)**<br>
I,J,L:片面にM4ナット3個,片面にM4ナット1個、合計5個
K:片面にM4ナット1個、片面に2個、合計3個<br>
(ナット18個:総計42個)<br>

**薄い180[mm]のフレーム2本(MN)**<br>
M:M4ナットを片面3,片面4個、合計7個<br>
N:M4ナットを片面2,片面5個、合計7個<br>
(ナット14個:総計56個)<br>

**Rのついた150[mm]のフレーム4本(OPQR)**<br>
O,P,Q,R:M4ナットを各面に2個ずつ,合計4個<br>
(ナット16個:総計72個)<br>

**四角い180[mm]のフレーム4本(STUV)**<br>
S:上面にM4ナットを4個、後ろ面にM4ナットを2個、下面にM4ナットを2個、合計8個<br>
T:上面にM4ナットを2個、下面にM4ナットを2個、合計4個<br>
U:上面にM4ナットを2個、後ろ面にM4ナットを2個、下面にM4ナットを2個、合計6個<br>
V:上面にM4ナットを2個、下面にM4ナットを2個、合計4個<br>
(ナット22個:総計94個)<br>

**四角い70[mm]のフレーム4本(WXYZ)**<br>
W,Y:片面にM4ナット2個、90度傾けてM4ナット1個、合計3個<br>
X,Z:片面にM4ナット2個、90度反対に傾けてM4ナット1個、合計3個<br>
(ナット12個:総計106個)<br>
---

## 手順②天板の作成
仮組みなのでゆるくねじを締めてください。<br>
三角ブラケットの表面の穴がある方が外装側になります。向き注意<br>
**必要なもの**<br>
- 黒ねじ×16個<br>
- アルミフレーム(ABCD, EF)<br>
- 三角ブラケット(8個)<br>
- 丸形ブラケット(4個)<br>
- T字ブラケット(2個)<br>
①A,B,C,Dを時計回りに、EとFも三角ブラケットでつなげます(黄色レンチ)<br>


②角は丸形ブラケットを付属のネジ2本でつなげます(黄緑色レンチ)<br>
　残りの一本はとっておいてください<br>



## 手順③天板のつなぎフレームの作成
**必要なもの**<br>
- 黒ねじ×6個<br>
- アルミフレーム(G,H)<br>
- T字ブラケット(2個)<br>
①Eの前面にGをT字ブラケットでつなげます<br>
　Fの後面にHをT字ブラケットでつなげます<br>


※このパーツはとりあえず完成です。あとはセンサー類を取り付けてから組み立てます。<br>

## 手順④上面の作成
- 黒ねじ×18個<br>
- アルミフレーム(IJKLD, MN)<br>
- 三角ブラケット(6個)<br>
- L字ブラケット(2個)<br>
- L字金属板(2個)<br>
- 丸形ブラケット(4個)<br>
同じよう三角ブラケットでつなげます。<br>
写真のようにM,NにL字ブラケットとL字板を取り付けてください。

後面からみた写真

四隅に丸形ブラケットを取り付けます。

## 手順⑤底面の作成
**必要なもの**<br>
- 黒ねじ×8個<br>
- アルミフレーム(STUV, WXYZ)<br>
- 三角ブラケット(4個)<br>
図のように三角ブラケットをとりつけます。<br>
このとき、UとSフレームの中心に印をつけて、70mmフレームが左右対称に取り付けれるようにします。<br>




## 手順⑥上面と底面をつなげる
**必要なもの**<br>
- 黒ねじ×24個<br>
- ステンレスネジ(8個)<br>
- アルミフレーム(OPQR)<br>
- 三角ブラケット(12個)<br>
- 四角ブラケット(4個)<br>

左からOPQRです。図のように参画ブラケットを取り付けます。


作成した底面に図のように取り付けます。


作成した上面に図のように取り付けます。

ここで、Sフレームを残りのボディに取り付けます。<br>
四角ブラケットはネジ穴がある方が外装側になるようにします。<br>

大きな穴からステンレスネジを通します。

この形でボディの全面にとりつけます。




組み立て終わったら、位置を合わせてネジを固めに締めていきます。<br>
ひとまず完成です。センサを取り付けてから天板とボディをとりつけます。<br>

---
[indexに戻る](../index.md)
|[assenbleに戻る](../2_assemble.md)
|[次のページ](./2-3.%20caster.md.md)

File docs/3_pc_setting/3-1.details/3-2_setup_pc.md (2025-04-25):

## PC設定

cube-petit用のPCで設定を行います。

## ネットワーク設定 & git net-toolsの導入

無線Wifiもしくは有線イーサネット接続をします。

詳細は[GithubのReadmeを見てください](https://github.com/AiriYokochi/setup_cube_petit/tree/feature/ros2_jazzy)

ターミナルを開いて以下コマンドを実行します。

```
sudo apt install -y git
mkdir -p ~/work && cd ~/work/
git clone https://github.com/AiriYokochi/setup_cube_petit.git -b feature/ros2_jazzy
```

①以下のコマンドを叩くとPCの全般の設定が始まります。
パスワードを求められたらパスワードを入力してください。
壁紙の変更、サイドバーを隠す、スリープモードの解除、Chromeのインストール
完了すると、背景画像が顔になります。
```
source ~/work/setup_cube_petit/setup_pc.bash
```
初回にChromeを開くとパスワードを求められますが、空白でエンターキーを二回押してください。

(オプション)②以下のコマンドを叩くと開発環境がインストールされます。
GitKraken, VSCode
```
source ~/work/setup_cube_petit/setup_dev_tools.bash
```

## SSHの設定

Cube petitのオプション機能を利用するためにはGithubのsbgisenグループに
アクセスできるSSH Keyの登録が必要です。
ターミナルで以下のコマンドを叩いて、エンターを3回押してください。
```
ssh-keygen
```
次に以下のコマンドを入力してください。
```
cat ~/.ssh/id_*.pub
```
表示された内容を以下のサイトにアクセスして入力してください。
https://github.com/settings/keys

緑色の[New SSH Key]ボタンをクリック

Titleにロボット名(自分がわかりやすいようにつける)
Keyに先程のコマンドの結果をコピペ(ssh~~~~~~~~ cube-petit@cube-petit-XX)

[Add SSH key]をクリック
`You have successfully added the key '<title>'.`と表示されたら成功です。

---

[indexに戻る](../index.md)
|[PC設定に戻る](../3_pc_setting.md)
|[次のページ](./3-2_setup_ros.md)

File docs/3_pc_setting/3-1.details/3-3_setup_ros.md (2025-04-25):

## ROS設定

cube-petit用のPCで設定を行います。

## ROS2 Jazzyの導入

ターミナルを開いて以下コマンドを実行します。
ROS2 Jazzyがインストールされます。

パスワードを求められたらパスワードを入力してください。
(yes)と表示されたらyesと入力しエンターキーを押してください。

```bash
source ~/work/setup_cube_petit/setup_ros.bash
```

SSHキーの登録をしていない場合はいくつかパッケージが入らずエラーが出ます。
以下のコマンドを実行してください。

```bash
cd ~/ros/src
rosdep install --from-path . --ignore-src -r -y

cd ~/ros
colcon build --symlink-install
```

---

[indexに戻る](../index.md)
|[PC設定に戻る](../3_pc_setting.md)
|[次のページ](./3-4_wire.md)

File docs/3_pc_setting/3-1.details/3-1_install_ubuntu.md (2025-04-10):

## Ubuntu24.04の導入

PCにLINUX OS [Ubuntu24.04](https://ubuntu.com/download/desktop)を導入します。
わからない方のみ下を見てください。

---
<br>
今回は1つのSSDの中にUbuntu24.04のみ(Windowsとは共存させない)を想定しています。<br>
**よってすでにWindowsが入っている場合は削除する作業をしています。**<br>
他のバージョンのUbuntuやWindowsなどを入れたい場合は別のSSDを用意することを<br>
おすすめします。

**Ubuntuとは**
Ubuntu（ウブンツ）は、誰でも無料で使えるLinux（リナックス）というOS（オペレーティングシステム）の一つです。<br>
使いやすさと安定性に定評があり、ソフトウェア開発やサーバー運用などの現場で広く使われています。<br>
特にプログラミングやロボット開発などでは、Ubuntuが標準環境として指定されていることも多く、初学者がLinuxを学ぶ入口としてもおすすめのOSです。<br>
Cube petitではUbuntu18.04, 20.04, 22.04, 24.04が対応しています。

**ver24.04について**
Ubuntu 24.04は、2024年4月にリリースされたLTS（Long Term Support：長期サポート）版です。<br>
LTS版は5年間の公式サポートがあり、企業や研究開発などで安心して使える安定版です。<br>
24.04にはロボットを動かすためのROS2 (Jazzyバージョン)が対応しています。<br>

---

## 必要なもの

- 利用予定のminiPC or Raspberry Pi5 & 電源
- キーボード
- マウス
- モニタ、HDMIケーブル
- LiveUSBを作成する作業用PC
- Wifi環境もしくは有線LAN

---

## 手順①Live USBの作成
Ubuntu 24.04 公式サイト: http://releases.ubuntu.com/24.04/ <br>
<br>
参考：<br>
https://www.kkaneko.jp/tools/ubuntu/ubuntudesktop.html

---

## 手順②Bootメニューに入ってUSBを起動するように設定する
PCの画面をつけた瞬間に**Delete**か**F2**もしくは**F7**を連打する<br>
ここはPCによります。わからなければ型番で「型番 BIOS 」等でググってください。<br>

BIOS画面(シンプルでだいたい青か白い画面)に入ったらOK<br>
そのままPCが起動したら電源を消してもう一度やり直す。<br>
**Boot**メニューを探し、優先順位を**USB**に変更する<br>

**Save&Exit**を選択肢終了する。<br>

---

## 手順③Ubuntu24.04のインストール
GRUB画面にきたら「Try or Install Ubuntu」を選択
デスクトップ画面が出たら左上のアプリをクリック

英語を設定しNextをクリック0



Nextをクリック

日本語配列キーボード(Enterがでかいことが多い、2キーの上が`"`)ならJapaneseを
英字配列キーボード(Enterが小さいことが多い、2キーの上が`@`)ならEnglishを選択
Nextをクリック

有線もしくはWifiを選択してネットワークに接続する
Nextをクリック

Skipをクリックする(Updateするとスタックする事例あります)



Install Ubuntuを選択してNextをクリック


Interactive instalattionをクリック、Nextをクリック

Default selectionを選択してNextをクリック

2つチェックを入れてNextをクリック

Erase disk and install Ubuntuをクリック

Your name：名前を入れる(cube-petit)<br>
Your computer name：PC名を入れる(一意であれば何でもいい、自分の名前など)<br>
Passworf Confirm Passwordは同じものを入れる<br>
<br>
上のチェックボックスは<br>
　自動ログインしたいときはチェックを入れない(ロボット機体など)<br>
 　毎回パスワードをうちこんで起動したい場合はチェックを入れる(自分のPCなど)<br>
下のチェックボックスはチェックを入れない<br>


Asia/Tokyoを選択してNextをクリック

Installをクリック。数分待機する

Restart Nowをクリック


**「Please remove the installation medium, Then press Enter」**
という文字が表示されたら、USBを抜いてEnterキーを押す

## 端末(Terminal)を起動する方法
デスクトップ上で右クリック→Open in Terminal

---

[indexに戻る](../index.md)
|[PC設定に戻る](../3_pc_setting.md)
|[次のページ](./3-2_setup_pc.md)

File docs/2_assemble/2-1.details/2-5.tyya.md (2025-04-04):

## タイヤの制作

タイヤを制作します

---

## 必要な工具

- 六角レンチ
- 瞬間接着剤

---

## 部材

- タイヤ4本
- ホイール4つ
- インナースポンジ4本

---

## 手順①タイヤにインナースポンジをはめる

## 手順②タイヤにホイールをはめる

## 手順③瞬間接着剤を流す

---
[indexに戻る](../index.md)
|[assenbleに戻る](../2_assemble.md)
|[次のページ](./2-2.%20almi_frame.md)

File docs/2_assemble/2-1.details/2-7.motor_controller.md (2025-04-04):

## モーターコントローラの配線

モーターコントローラの配線をします。

---

## 必要な工具

- はんだ
- ニッパー
- ワイヤーストリッパー
---

## 部材

- モーターコントローラ
- ケーブル
- コネクタ

---

## 手順①電源コネクタの作成

## 手順②CAN用コネクタの作成

## 手順③コルゲートチューブ

## 手順④電源つけてボタン押して設定する

①電源接続
モータを12V電源に接続します。

②モータコントローラの設定
モータコントローラ(C610)の黒いボタンを1回押す(LEDは光らない)
設定したいIDの回数分、ボタンを押します。
2個使用するので、1個は1回、もう1個は2回押します。
完了するとオレンジに1度光ります。
成功すると音がなってLEDがIDの回数分だけ緑で光ります。

---
[indexに戻る](../index.md)
|[assenbleに戻る](../2_assemble.md)
|[次のページ](./2-2.%20almi_frame.md)

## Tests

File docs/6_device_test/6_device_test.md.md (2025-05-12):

# デバイステスト
<br>
センサ・モータ以外のデバイスのテスト
<br>

## 配線チェック

## 電源チェック

## 起動チェック

## ネットワークチェック

## マイク・スピーカチェック

---
[indexに戻る](../index.md)

以下のコマンドを叩いて[OK]の文字が出れば合っています。
```
source ~/setup_cube_petit/shell_scripts/udev_check.sh
```

---

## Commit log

2025-04-28 add assemble
2025-05-01 add motor_controller
2025-05-07 add sensor
2025-05-12 add wire
2025-05-12 add 2d dwg file
    [1mm_clear_face1_size_x1.dwg, 1mm_clear_face1_size_x1.idw, 2mm_color_face2_size_x1.dwg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]
2025-05-12 add almi parts
    [L_almite_braket_3mm_x2.ipt, LiDAR_LD19_LD_Plate_1mm_x1.ipt, head_T_braket_alminium_3mm_x2.ipt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]
